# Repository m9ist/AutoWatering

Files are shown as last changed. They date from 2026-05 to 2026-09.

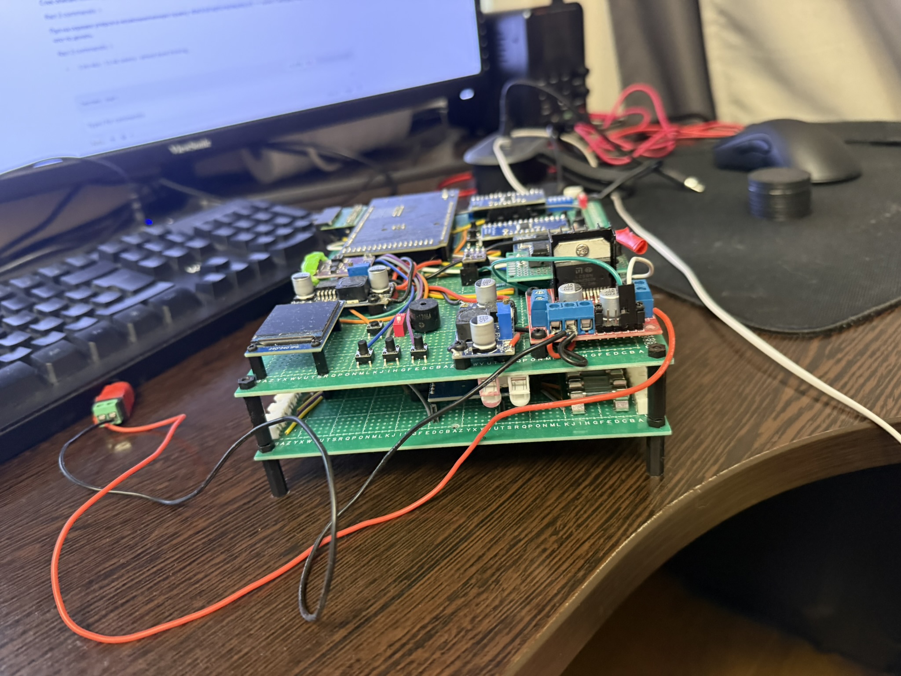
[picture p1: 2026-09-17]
docs/photos/IMG_0999.JPEG

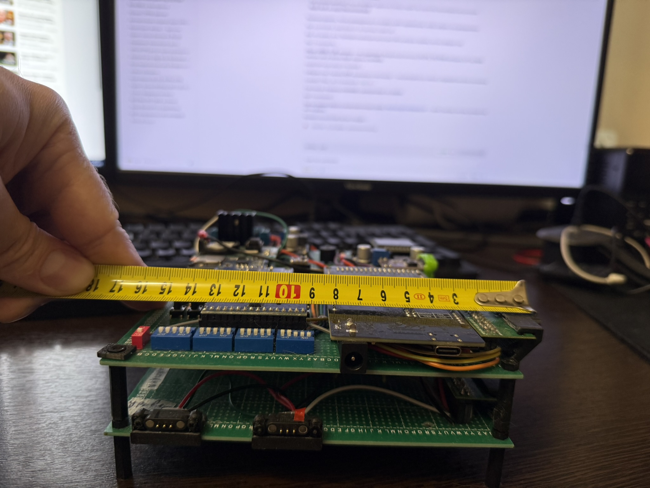
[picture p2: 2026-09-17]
docs/photos/IMG_0997.JPEG

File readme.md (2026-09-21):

# Автоматическая поливка растений

Система автоматического полива комнатных растений на базе Arduino Mega2560 + ESP8266. Поддерживает до 16 растений, управляется через Telegram, собирает данные с датчиков влажности почвы и отображает их на дисплее; логи и графики — в Grafana на домашнем сервере.

## Текущее состояние

- Проект в боевой эксплуатации (3–5 растений подключено)
- Управление поливом через Telegram-бота **aw-server** на домашнем сервере (`server/` этой репы)
- ESP — headless MQTT-шлюз: единственное соединение — локальный Mosquitto (см. [ADR-0001](docs/adr/0001-local-mqtt-broker.md))
- Логи ESP и метрики (температура, влажность воздуха, RAM, влажность почвы по растениям) — в Loki/Grafana, дашборд «Автополив»
- Уведомления в чат о переходах ESP онлайн/офлайн (LWT брокера)
- Ручной полив через кнопки на плате; ежедневный автополив — по команде `/daily`
- Диагностика подключения клапанов через датчик тока ACS712 (`/checkvalves`, кнопка на плате, статус в отчёте о каждом поливе)
- Оживление залипших после простоя клапанов: сухой прогон «дожим + щелчки» (`/wakeup`, либо кнопка проливки растения при выключенном тумблере помпы)

## Архитектура

```
[Telegram]        [Grafana/Loki (дашборд «Автополив»)]
     │                      ▲
     ▼                      │ логи + метрики
[aw-server]  ── Python-сервис на домашнем серваке (код: server/)
     │  команды aw/cmd ↓ · логи aw/log/# ↑ · стейт aw/state ↑ · события aw/event ↑
     ▼
[Mosquitto]  ── локальный MQTT-брокер (LAN, user/pass)
     ▲
     │ единственное внешнее соединение ESP
[ESP8266]    ── headless: WiFi, NTP, OTA, MQTT
     │  UART, текстовый JSON-протокол
[Arduino Mega2560] ── помпы, клапаны, датчики, дисплей, RTC, кнопки, SD-лог
```

**Arduino Mega2560** управляет всем железом, хранит стейт в EEPROM, исполняет команды полива, пишет логи на SD (офлайн-фолбэк).

**ESP8266** — тонкий шлюз: форвардит Команды из `aw/cmd` в UART (с валидацией границ), публикует кадр стейта Mega в `aw/state` как есть (retained), шлёт логи в `aw/log/esp` (при обрыве — RAM-кольцо с досылкой), держит LWT `aw/online`. Прошивается по OTA.

**aw-server** (Python, `server/`) — телеграм-бот (whitelist чатов), мост логов в Loki, метрики из стейта, уведомления о статусе ESP. Деплой — docker-стек в приватной инфра-репе homelab.

## Компоненты

| Компонент | Модель | Описание |
|---|---|---|
| Плата | Mega2560+WiFi-R3-AT328-ESP8266-32MB-CH340G | Arduino Mega + ESP8266 на одной плате |
| DC-DC преобразователь | LM2596S | 2 шт. Питание от внешнего БП 20V: один понижает до 5V (клапаны, электроника), второй до 12V (помпы) |
| Дисплей | IPS TFT ST7789 240×240 (ZJY-IPS130-V2.0) | Статус системы. [Схема подключения](https://simple-circuit.com/wp-content/uploads/2019/06/arduino-st7789-color-tft-240x240-pixel-interfacing-circuit.png) |
| RTC | DS1302 (чип DS1307) | Часы реального времени. [Документация](https://www.nookery.ru/ds1302-in-arduino/) |
| Помпа | R385 + драйвер MX1508 (чип L298N) | 2 шт. Перистальтические, активная выбирается из прошивки (ADR-0002). [Документация L298N](https://robotchip.ru/obzor-drayvera-motora-na-l298n/) |
| Клапаны | DC 5V HUXUAN электромагнитные | 16 шт, по одному на растение. Драйвер: WAVGAT ULN2003 5V 4-phase |
| Управление клапанами | 74HC595 сдвиговые регистры (3 шт) | Управление 16+ клапанами через 3 пина. [Урок](https://alexgyver.ru/lessons/74hc595/), [подключение](https://uscr.ru/kak-podklyuchit-sdvigoviy-registr-k-arduino/) |
| Датчики влажности почвы | HD-38 (SZYTF Soil Moisture Sensor) | 16 шт, аналоговые, ёмкостные. [Пример кода](https://github.com/vrxfile/test_arduino_sensors_modules/blob/master/capacitive_moisture_test/capacitive_moisture_test.ino), [описание](https://myduino.com/product/jhs-273/) |
| Мультиплексер | CD74HC4067 | 16-канальный, для датчиков влажности и кнопок. [Документация](https://arduinolab.pw/index.php/2017/07/17/16-kanalnyj-analogovyj-multipleksor-cd74hc4067/) |
| Датчик расхода воды | HESAI YF-S401 | Учёт пролитой воды в мл. [Документация](https://wiki.iarduino.ru/page/sensor-water-flow/) |
| Датчик тока | ACS712 20A | Диагностика клапанов |
| Датчик темп./влажности | GY-SHT30-D (чип SHT30) | Температура и влажность воздуха |
| Датчик уровня воды | XKC-Y25-NPN 5–12V | Бесконтактный. [Документация](https://wiki.amperka.ru/products:sensor-liquid-level-contactless) |
| SD-ридер | hw-125 (чип B108) | Логирование |

## Команды Telegram

Бот живёт в aw-server; команды принимаются только из whitelist-чатов.

| Команда | Описание |
|---|---|
| `/water plantX Yml` | Полить растение X на Y мл. Пример: `/water plant3 50ml` |
| `/config plantX Yml` | Установить дневную норму полива. Пример: `/config plant2 20ml` |
| `/state` | Последний стейт из retained `aw/state` (влажность, температура, свободная память, активная помпа) |
| `/daily` | Запустить ежедневный цикл полива вручную |
| `/checkvalves` | Проверить подключение всех активных клапанов (по дельте тока ACS712) |
| `/pump` | Переключить активную помпу на другую; результат — в `/state` |
| `/wakeup plantX [AxBms CxDms]` | Расходить залипший клапан X: щелчки всухую, помпа не включается. Без аргументов — `3x2000ms + 7x300ms`. Пример: `/wakeup plant3 5x1500 10x400` |
| `/help` | Справка по командам |

Графики влажности/климата — в Grafana (ASCII-графики в чате выпилены, issue [#20](https://github.com/m9ist/AutoWatering/issues/20)). Периодическая сводка стейта отключена (`HOURLY_SUMMARY_INTERVAL_S=0` в деплое).

## Начало работы

**Среда разработки:** [VS Code](https://code.visualstudio.com/) + [PlatformIO](https://platformio.org/platformio-ide)

Проект содержит две прошивки в `platformio.ini`:
- `megaatmega2560` — для Arduino Mega
- `esp` — для ESP8266 (загрузка по OTA на адрес `192.168.1.96`)

**Обязательные шаги перед сборкой:**

1. Создать файл `src/SecretHolder.cpp` (вне git) и реализовать методы:
   ```cpp
   String ssid()         { return "your_wifi_ssid"; }
   String wifiPasswork() { return "your_wifi_password"; }
   String mqttUser()     { return "esp"; }
   String mqttPassword() { return "<пароль учётки esp из sops стека mqtt>"; }
   ```

**Native-тесты** (парсер команд, RAM-кольцо логов, обработчик `aw/cmd`) — способ запуска описан в комментарии в конце `platformio.ini`.

**aw-server** (`server/`): Python 3.12, тесты `python -m pytest`; конфиг через env (см. `server/aw_server/config.py`). Деплой — стек `watering` в приватной репе homelab (там же брокер, стек `mqtt`).

## Протокол

**Arduino ↔ ESP (UART, JSON с ключом `"c"`):**

| Направление | Команда | Описание |
|---|---|---|
| ESP → Arduino | `esp_water` | Полить растение |
| ESP → Arduino | `esp_plant_conf` | Настроить дневную норму |
| ESP → Arduino | `esp_daily` | Запустить ежедневный полив |
| ESP → Arduino | `esp_check_valves` | Проверить подключение клапанов |
| ESP → Arduino | `esp_pump` | Переключить активную помпу на другую |
| ESP → Arduino | `esp_ntp` | Синхронизировать время |
| Arduino → ESP | `state` | Обновлённый стейт системы |
| Arduino → ESP | `arduino_tg` | Сообщение для человека (уходит Событием в `aw/event`) |

**MQTT (ESP ↔ aw-server, брокер Mosquitto):**

| Топик | Направление | Что | Retained |
|---|---|-----|---|
| `aw/cmd` | aw-server → ESP | JSON UART-протокола, passthrough (ESP валидирует границы) | нет |
| `aw/state` | ESP → aw-server | кадр `state` от Mega как есть | **да** |
| `aw/log/esp` | ESP → aw-server | строки лога `{ts, lvl, msg}` → Loki | нет |
| `aw/event` | ESP → aw-server | `{type, text}` — для Telegram | нет |
| `aw/online` | LWT | `1`/`0` — статус ESP (уведомления + панель в Grafana) | да |

## Калибровка расхода воды

Объём полива человек задаёт в миллилитрах, а помпа умеет только «крутиться
столько-то времени». Переводной коэффициент — практический расход помпы
в мл/с; по нему считается длительность автополива и `Expected ml` в отчёте.

Помпы физически разные, поэтому коэффициент у каждой свой
([src/Pomp.h](src/Pomp.h)):

| Помпа | Константа | Расход |
|---|---|---|
| 1 (main) | `POMP_FLOW_ML_PER_SEC_1` | 2.1 мл/с |
| 2 (spare) | `POMP_FLOW_ML_PER_SEC_2` | 3.2 мл/с |

Код берёт нужную через `pumpFlowMlPerSec(pumpIdx)` — в том числе на пробе
резерва, когда полив уходит на неактивную помпу.

Порядок калибровки:

1. Включить тумблер мотора (иначе кнопка запускает оживление клапана, а не
   полив), подставить под шланг растения мерный стакан.
2. Подержать кнопку проливки этого растения — льётся, пока кнопка нажата.
3. Взять из отчёта (экран и Telegram) `Expected ml` и записать реально
   налитый объём по стакану.
4. Новое значение = текущее × (налито по стакану / `Expected ml`). Несколько
   проливов разной длительности дают более честное среднее: короткие
   искажает разгон помпы.
5. Прописать новое значение в константу **той помпы, которая лила** (номер
   есть в том же отчёте, строка `Pump N`) и перепрошить Mega.

Кнопка на корпусе всегда льёт активной помпой — чтобы откалибровать вторую,
переключись на неё командой `/pump` и не забудь вернуть обратно.

Делить объём на `Duration` из отчёта нельзя: `Duration` — это весь полив
целиком, включая паузы по 200 мс на открытие и закрытие клапана, когда помпа
ещё (уже) не качает. `Expected ml` считается от окна работы самой помпы, так
что отношение «налито / Expected» этой погрешности не содержит.

`Real ml` в том же отчёте — показания расходомера YF-S401, они меряют то же
самое независимо, но сами нуждаются в проверке стаканом; ориентир при
калибровке — стакан, а не они.

Значение зависит от помпы, её скорости и высоты подъёма шланга — после любой
переделки гидравлики калибровку надо повторить, по каждой помпе отдельно.

## Известные проблемы и ограничения

- Физические соединения на pogo-pin разъёмах нестабильны — клапаны могут выпасть
- Ежедневный автозапуск полива по расписанию пока не реализован (только через `/daily`)
- Команды при офлайн-ESP не доставляются (clean-session + QoS0) — бот честно предупреждает в ACK
- Резерв помпы проверяется вероятностно (10% поливов уходят на неактивную помпу); при мёртвом резерве эти поливы уходят в никуда, вердикт выносит человек по `/state` (ADR-0002)
- У брокера нет ACL — доводка в issue [#19](https://github.com/m9ist/AutoWatering/issues/19)

## Команда проекта

- tg [@m9ist](https://t.me/m9ist)

---
*Используйте на свой страх и риск. Автор не компетентен в электронике.*

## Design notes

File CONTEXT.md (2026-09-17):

# Автополив

Система автополива до 16 комнатных растений: Mega2560 управляет железом,
ESP8266 связывает её с внешним миром через MQTT-брокер на домашнем серваке.

## Language

### Устройства и сервисы

**Mega**:
Arduino Mega2560, управляет железом (помпы, клапаны, датчики, дисплей, SD).
_Avoid_: ардуина (двусмысленно — ESP тоже Arduino-прошивка)

**ESP**:
ESP8266, headless-шлюз между Mega (UART) и брокером (MQTT). Своего
пользовательского интерфейса не имеет.

**aw-server**:
Серверный сервис на deb: телеграм-бот автополива, мост логов в Loki,
приёмник телеметрии. Код — в `server/` этой репы, деплой — в репе homelab.
_Avoid_: бот (это только одна из его ролей), мост

**Брокер**:
Локальный Mosquitto на серваке deb — единственная точка подключения ESP
и общая шина для будущих домашних интеграций.
_Avoid_: Dealgate (внешний брокер, ESP к нему не подключается — см. ADR-0001)

### Потоки данных

**Команда**:
JSON с ключом `c`, адресованный Mega. Формат един на всём пути
Telegram → aw-server → MQTT (`aw/cmd`) → ESP → UART; ESP валидирует
и форвардит, не переформатируя.

**Стейт**:
Снимок состояния системы (растения, климат, флаги), который Mega
периодически шлёт наверх. Последний стейт лежит retained в `aw/state`.

**Событие**:
Сообщение от ESP/Mega, предназначенное человеку в Telegram (подтверждения,
отказы Команд, тревоги). Публикуется в `aw/event`, доставляет aw-server.

**Лог-поток**:
Строки логов ESP, уходящие в `aw/log/esp` и далее в Loki. Дублируются
по старому пути UART → Mega → SD (офлайн-фолбэк).

### Полив

**Растение**:
Позиция 0..15: клапан + датчик влажности + дневная норма (мл).

**Дневной полив**:
Полив всех растений по их нормам одной командой (`/daily`); запускается
вручную, автозапуск по расписанию — в планах.

**Норма**:
Настроенный дневной объём воды растения, мл (`dailyAmountMl`).
_Avoid_: конфиг растения

**Помпа**:
Перистальтическая помпа R385 на драйвере MX1508. Их две: `pump1` (D6) и
`pump2` (D5) — номера позиционные и неизменные, роль «активная/резерв»
задаётся отдельно.
_Avoid_: насос, мотор

**Активная помпа**:
Помпа, на которой идут поливы (`State::activePump`). Переживает ребут,
меняется Командой `esp_pump` (`/pump` в Telegram). Вторая при этом —
резерв.

**Проба резерва**:
Полив, который с вероятностью 10% уходит на неактивную помпу вместо
активной, чтобы знать, жива ли она, до того как умрёт активная. В саммари
полива помечается `(spare probe)`. Вердикт «резерв мёртв» выносит человек
по `/state`, автоматики нет (ADR-0002).
_Avoid_: ротация помп, тест помпы

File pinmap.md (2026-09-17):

# Карта пинов Arduino Mega2560

Источник правды — код `D:\arduino\sketch_auto_watering\src`. Если код и эта таблица расходятся — побеждает код.

## Сводка по физическому разделению на 2 платы

Из `src/additinal_info.txt`: «Пины на нижней плате: 22-38d 0-7a».

| Плата | Что несёт | Пины Mega |
|---|---|---|
| **Верхняя (логическая)** | Mega+ESP-модуль, ST7789, RTC DS1302, MX1508 + 2 помпы, ACS712, SHT30, YF-S401, XKC уровень воды, hw-125 SD, пищалка, 4 кнопки UI, тумблер мотора | D2, D5, D6, D17, D19, D21, D27, D29, D31, D33, D37, D39, D41, D43, D45, D47, D50–D52, A0–A2, A12–A15 |
| **Нижняя (клапаны/датчики)** | 3× 74HC595 + 3× ULN2003, 16 клапанов, 3× CD74HC4067, 16 датчиков влажности, 16 кнопок проливки, 16 тумблеров клапанов | D18, D20, D26, D28, D30, D32, D34, D36, D38, A8–A11 |

Связь между платами — обычным кабелем (USB/гребёнка). На фабрике заказываем как 2 разные PCB.

## Цифровые пины Mega

| Пин | Назначение | Файл / макрос |
|---|---|---|
| **D2** | Датчик расхода воды YF-S401 (interrupt) | `Pomp.h` `PIN_WATER_FLOW_SENSOR` |
| **D5** | Помпа `pump2` (PWM → MX1508) | `Pomp.h` `PIN_POMP_SPARE` |
| **D6** | Помпа `pump1` (PWM → MX1508) | `Pomp.h` `PIN_POMP_MAIN` |
| **D17** | Тумблер мотора (физ. переключатель, INPUT_PULLUP) | `Pomp.h` `PIN_POMP_TURN_ON` |
| **D18** | SIG mux #3 — тумблеры клапанов 16шт (INPUT_PULLUP) | `Pomp.h` `PIN_MULTIPLEXER_PLANT_TURN_ON_SIG` |
| **D19** | I²C SDA → SHT30 | `Sensors.h` `PIN_TEMP_SDA` |
| **D20** | SIG mux #2 — кнопки проливки 16шт (INPUT_PULLUP) | `Pomp.h` `PIN_MULTIPLEXER_WATER_NOW_SIG` |
| **D21** | I²C SCL → SHT30 | `Sensors.h` `PIN_TEMP_SCL` |
| **D26** | Mux #1 S0 (датчики влажности) | `Sensors.h` `PIN_SERNSOR_S0` |
| **D27** | Кнопка выбора режима (INPUT_PULLUP) | `Screen.h` `PIN_MODE_BUTTON` |
| **D28** | Mux #1 S1 | `Sensors.h` `PIN_SERNSOR_S1` |
| **D29** | Кнопка вверх (INPUT_PULLUP) | `Screen.h` `PIN_UP_BUTTON` |
| **D30** | Mux #1 S2 | `Sensors.h` `PIN_SERNSOR_S2` |
| **D31** | Кнопка вниз (INPUT_PULLUP) | `Screen.h` `PIN_DOWN_BUTTON` |
| **D32** | Mux #1 S3 | `Sensors.h` `PIN_SERNSOR_S3` |
| **D33** | Кнопка проверки (INPUT_PULLUP) | `Screen.h` `PIN_CHECK_BUTTON` |
| **D34** | 74HC595 DS (data) | `Pomp.h` `PIN_REGISTER_DAT` |
| **D36** | 74HC595 STCP (latch) | `Pomp.h` `PIN_REGISTER_CS` |
| **D37** | TFT RES | `sketch_auto_watering.ino` `TFT_RES` |
| **D38** | 74HC595 SHCP (clock) | `Pomp.h` `PIN_REGISTER_CLK` |
| **D39** | TFT DC | `sketch_auto_watering.ino` `TFT_DC` |
| **D41** | RTC DS1302 ENA (RST/CE) | `AwClock.h` `PIN_ENA` |
| **D43** | RTC DS1302 DAT (I/O) | `AwClock.h` `PIN_DAT` |
| **D45** | RTC DS1302 CLK | `AwClock.h` `PIN_CLK` |
| **D47** | Пищалка (buzzer) | `AwLogging.h` `PIN_BUZZER` |
| **D50** | SPI MISO (hardware, не используется TFT'ом) | Mega hw |
| **D51** | SPI MOSI → TFT SDA (через делитель 5V→3.3V) | Mega hw |
| **D52** | SPI SCK → TFT SCL (через делитель 5V→3.3V) | Mega hw |

## Аналоговые пины Mega (часть в роли digital)

| Пин | Назначение | Файл / макрос |
|---|---|---|
| **A0** | Mux #1 SIG — 16 датчиков влажности почвы | `Sensors.h` `PIN_INPUT_SENSOR=0` (читается как `analogRead(0)`) |
| **A1** | Датчик уровня воды XKC-Y25 (analogRead, hi/lo) | `Sensors.h` `PIN_WATER_LEVEL` |
| **A2** | Датчик тока ACS712 | `Pomp.h` `PIN_AMPERAGE_SENSOR` |
| **A8** | Mux #2/#3 S3 (общая шина управления для двух кнопочных mux) | `Pomp.h` `PIN_PLANT_MULTIPLEXER_S3` |
| **A9** | Mux #2/#3 S2 | `Pomp.h` `PIN_PLANT_MULTIPLEXER_S2` |
| **A10** | Mux #2/#3 S1 | `Pomp.h` `PIN_PLANT_MULTIPLEXER_S1` |
| **A11** | Mux #2/#3 S0 | `Pomp.h` `PIN_PLANT_MULTIPLEXER_S0` |
| **A12** | SD (hw-125) MISO (software SPI!) | `AwLogging.h` `SD_MISO_PIN` |
| **A13** | SD MOSI | `AwLogging.h` `SD_MOSI_PIN` |
| **A14** | SD SCK | `AwLogging.h` `SD_SCK_PIN` |
| **A15** | SD CS | `AwLogging.h` `SD_CS_PIN` |

> SD на **программном** SPI (не на D50–D52), потому что hardware-SPI занят под TFT (даже если TFT работает только на запись, библиотека SdFat плохо уживается с делителями уровней — поэтому ушли на bit-bang на A12–A15).

## CD74HC4067 — 3 шт.

| # | Назначение | S0..S3 | SIG | Кол-во каналов |
|---|---|---|---|---|
| 1 | Датчики влажности почвы (HD-38) | D26/D28/D30/D32 | A0 | 16 |
| 2 | Кнопки проливки растений (тактильные) | A11/A10/A9/A8 (общие с #3) | D20 | 16 |
| 3 | Тумблеры включения растений (физические) | A11/A10/A9/A8 (общие с #2) | D18 | 16 |

## 74HC595 — 3 шт. в каскаде

Управление: DS=D34, SHCP=D38, STCP=D36. OE и MR — на VCC/GND статически.

В каждом регистре используется **только Q1..Q7** (7 выходов из 8). 3 × 7 = 21 канал, на клапаны идёт 16, остальные пустуют. Логика — в `Pomp.h::patchValveId`:

```c
if (id < 7)  return id + 1;   // valves 0..6  → register1.Q1..Q7
if (id < 14) return id + 2;   // valves 7..13 → register2.Q1..Q7
else         return id + 3;   // valves 14..15 → register3.Q1..Q2
```

С каждого регистра Q1..Q7 → IN1..IN7 соответствующего ULN2003 → клапан + флайбэк-диод (диод уже в ULN2003, отдельные не нужны).

## ULN2003 — 3 шт.

Стоят сразу после 74HC595, по одной на регистр. Питание (COM, pin 9) — от шины **5V клапанов** (отдельная от 5V логики).

**Важная особенность подключения клапанов:** ULN2003 — это сборка open-collector NPN, она **замыкает массу**, а не подаёт плюс. Поэтому:

- **+5V (шина клапанов)** подаётся на **все 16 клапанов** одной общей шиной (плюсовая ножка каждого клапана).
- **Минусовая ножка** каждого клапана уходит на индивидуальный выход OUT драйвера ULN2003.
- COM-пин ULN2003 (pin 9) тоже подключён к **+5V шины клапанов** — для встроенных freewheel-диодов.

**Что это даёт для кабельного хозяйства / будущей PCB-перепланировки:**
один толстый провод +5V (общий) + 16 сигнальных в плоском шлейфе. Хорошо для будущей архитектуры с отдельной саб-платой клапанов и USB-кабелем между платами.

## Силовая часть (as-is)

```
USB-C PD-trigger (модуль с DIP-switch, 5/10/15/20V) → 20V
   │
   ├── LM2596S #1 → 12V → MX1508 → 2 помпы R385
   │
   └── LM2596S #2 → 5V (общая шина) → клапаны через ULN2003
                                    + Mega (на пин 5V), регистры, мультиплексоры,
                                      датчики, дисплей через 3.3V LDO самой Mega
```

**Важно:** в текущей as-is одна общая шина 5V на всё. Разделение на «5V клапанов» и «5V логики» — в [backlog.md](backlog.md), на рефакторинг.

3.3V для TFT берётся с самой Mega; SPI-сигналы (SCK/MOSI/DC/RES) проходят через резистивные делители 5V→3.3V (R 2.2k + R 3.3k).

## Подключение MX1508 (помпы R385)

Реверс не нужен — помпы крутятся только в одну сторону. PWM на одном входе пары, второй вход — на GND:

| Канал MX1508 | Подключение |
|---|---|
| `pump1` | IN1 = D6 (PWM), IN2 = GND. Помпа между OUT1 и OUT2 (или OUT2 и GND, если плата так разведена). |
| `pump2` | IN3 = D5 (PWM), IN4 = GND. Аналогично. |

Питание VCC драйвера = **12V** (с LM2596S #1). Логическая сторона MX1508 (VCC IO) — обычно объединена с VCC-силовой, нужно проверить по конкретному модулю.

## Питание Mega

**Внешний 5V с LM2596S #3 идёт прямо на пин `5V` Mega-модуля** (минуя встроенный регулятор Mega). Та же шина уходит и на нижнюю плату (питание регистров, мультиплексоров, ULN2003 — последний только в COM, не на VCC).

USB-разъём Mega остаётся для прошивки/отладки, но в постоянной работе питание идёт по 5V-пину.

## Разъёмы на плате (as-is)

| Группа | Кол-во | Тип | Контактов | Где расположен |
|---|---|---|---|---|
| Клапаны | 16 | Pin header 2.54 мм (гребёнка под Dupont) | 2 (V+ и сигнал) | нижняя плата |
| Датчики влажности | 16 | Pin header 2.54 мм | 3 (V+, GND, A) | нижняя плата |
| Помпы | 2 | DC barrel jack 5.5×2.1 мм («DC 2.1») — кабель идёт от MX1508 | 2 (V, GND) | верхняя плата (рядом с MX1508) |
| YF-S401 расходомер | 1 | Pogo-pin 3-контакта (на плате — ответная часть) | 3 (V+, GND, signal) | нижняя плата |
| XKC-Y25 уровень воды | 1 | Pogo-pin 3-контакта | 3 (V+, GND, signal) | нижняя плата |
| SHT30 (I²C) | 1 | 2.54 мм гребёнка | 4 (V, GND, SCL, SDA) | верхняя плата |
| RTC DS1302 (модуль) | 1 | 2.54 мм гребёнка | 5 (VCC, GND, CLK, DAT, RST) | верхняя плата |

> **На рефакторинг:** заменить pin header'ы 2.54 мм на разъёмы с замком (KK 254 / JST EH 2.5 мм) — снимет проблему «клапаны выпадают» из исходного readme.

## Архитектура датчиков с pogo

Датчики (расходомер, уровень воды) — внешние устройства с 3-проводным кабелем. На конце кабеля припаян pogo, на плате — ответный pogo. Так датчик легко отстёгивается для обслуживания.

Дальше с pogo'a на плате:
- **V+ → шина 5V** (на той же плате)
- **GND → шина GND** (на той же плате)
- **Сигнал → межплатный USB → Mega** (на верхней плате — D2 для расходомера, A1 для уровня воды)

То есть pogo физически стоит на нижней плате, а сигнал везётся на верхнюю через межплатный кабель.

## Межплатный коннектор

На обеих платах стоит **USB 3.0 (тип A или B)**. Между платами — обычный USB 3.0-кабель, по 9 жил которого передаются: 5V, GND и нужные сигналы между нижней и верхней платой.

Маппинг конкретных сигналов на пины USB-разъёма зафиксируем при разводке.

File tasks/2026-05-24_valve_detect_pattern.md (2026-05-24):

# Задача: подобрать паттерн детекции подключённого клапана через ACS712

Дата: 2026-05-24

## Контекст

На линии питания клапанов стоит датчик тока ACS712 (пин `A2`). Уже есть базовая
функция `Pomp::checkValveConnected(id)` ([src/Pomp.h:326](../src/Pomp.h#L326)),
которая один раз включает клапан, мерит дельту тока и сравнивает с
`THRESHOLD_MA = 780`. Текущий порог не откалиброван (по комментарию рядом
дельта подключённого клапана ~131 mA, а сравнивается с 780 → всегда
DISCONNECTED).

Цель сегодня — **не править порог на глаз**, а собрать данные многократных
включений/выключений и понять, какой паттерн надёжно отличает «клапан
подключён» от «клапана нет».

## Тестовый стенд

- Slot **0** — клапан **подключён**.
- Slot **1** — клапана **нет** (висит «в воздухе»).
- Остальные слоты в этой сессии не используем.

Имея данные с этих двух соседних слотов, можно прямо сравнить распределения
и решить, по какому признаку отличать (дельта среднего, дисперсия,
N-из-M повторов и т.п.).

## Что делаем

### Идея измерения

Клапан — это соленоид. При подаче питания получаем **inrush-пик** тока в
момент открытия, дальше потребление падает. Используем сам факт пика как
критерий «клапан подключён»: на пустом слоте пика быть не должно.

Заранее не знаем ни длительности пика, ни формы кривой → **снимаем
полный профиль тока во времени** и анализируем уже на компе. На ардуине
никаких пороговых решений сегодня не принимаем.

#### Профиль одного ON/OFF цикла

- `base` — один замер `measureDcAvg(N_BASE_SAMPLES)` перед ON.
- **ON-окно**: 2 секунды с шагом 30 мс ⇒ ~67 точек.
- **TAIL-окно**: 1 секунда после OFF с шагом 30 мс ⇒ ~33 точки (смотрим
  спад; пригодится, если у пустого слота есть короткие выбросы и
  отличать придётся по форме, а не только по амплитуде).
- `GAP_BETWEEN_CYCLES_MS` — пауза перед следующим циклом.

Замеры за одну итерацию собираем в **локальные массивы int** на стеке
(~67 + 33 = ~100 элементов × 2 байта = ~200 байт). После цикла дампим
в Serial одной CSV-подобной строкой и переиспользуем буферы для
следующего цикла. На SRAM Mega2560 этого хватит без хип-фрагментации.

Грубый псевдокод одного цикла:

```
base = measureDcAvg(N_BASE_SAMPLES)
turnOnValve(id)
for k in 0..ON_SAMPLES-1:
    on[k] = ACS.mA_DC()
    wait_until(start_on + (k+1)*SAMPLE_PERIOD_MS)
    wdt_reset()
turnOffValve(id)
for k in 0..TAIL_SAMPLES-1:
    tail[k] = ACS.mA_DC()
    wait_until(start_off + (k+1)*SAMPLE_PERIOD_MS)
    wdt_reset()
dumpProbeLine(id, round, iter, base, on, tail)
delay(GAP_BETWEEN_CYCLES_MS)
```

Watchdog: текущий `WDTO_8S` ([sketch_auto_watering.ino:78](../src/sketch_auto_watering.ino#L78)).
Один цикл ≈ 2с + 1с + GAP + дамп ≈ 3.3с. `wdt_reset()` обязательно
**внутри** циклов замеров.

### Формат лога

Одна строка на цикл, чтобы потом легко распарсить:

```
VALVE_PROBE id=<id> round=<r> iter=<k> base=<mA> on=<v0>,<v1>,...,<v66> tail=<v0>,<v1>,...,<v32>
```

Сводку по слоту на ардуине считать **не нужно** — всё считаем на компе
по логу.

### Параметры (константы)

В начале метода:

- `N_BASE_SAMPLES = 10` — замеров для усреднённого baseline.
- `SAMPLE_PERIOD_MS = 30` — шаг между точками профиля.
- `ON_WINDOW_MS = 2000` ⇒ `ON_SAMPLES = ON_WINDOW_MS / SAMPLE_PERIOD_MS`.
- `TAIL_WINDOW_MS = 1000` ⇒ `TAIL_SAMPLES = TAIL_WINDOW_MS / SAMPLE_PERIOD_MS`.
- `GAP_BETWEEN_CYCLES_MS = 200` — клапан без тока закрывается быстро.
- `CYCLES_PER_PROBE = 3` — циклов ON/OFF на одну «проверку» слота.
- `ANCHOR_ROUNDS = 3` — раундов «якорь + рандом».
- `ANCHOR_SLOT = 0` — заведомо подключённый слот.

### Порядок прогона

Не просто `[0, 1]`, а с чередованием якоря и случайного слота, чтобы
исключить дрейф midpoint и сравнить подключённый клапан с
«заведомо пустым» в одних и тех же условиях:

```
повторить ANCHOR_ROUNDS раз:
    probe(ANCHOR_SLOT)            // 3 цикла ON/OFF на slot 0
    rnd = random(1, 16)           // 1..15, пустой слот на стенде
    probe(rnd)                    // 3 цикла ON/OFF
```

Итого на старте: 3 раунда × 2 слота × 3 цикла = **18 циклов** ON/OFF.
Время прогона ≈ 18 × 3.3с ≈ **60 секунд**.

### Интеграция

- **Новый публичный метод в `Pomp.h`** (рабочее имя
  `runValveProbe(AwLogging&)` — уточним при реализации).
- **Запуск** — из `loop()` в
  [sketch_auto_watering.ino:267](../src/sketch_auto_watering.ino#L267).
  Сейчас по `isCheckButtonPressed()` дёргается `sensors.tmpLoop`. Заменяем
  на вызов нового метода. `sensors.tmpLoop` пока трогать аккуратно — по
  умолчанию просто заменить вызов.
- **Помпу НЕ включаем** в этом сценарии. Только клапаны и ACS712.

## Что НЕ делаем сегодня

- Не подбираем финальный `THRESHOLD_MA` и не правим `checkValveConnected`
  по итогам одного прогона. Сначала смотрим данные, потом — отдельным
  шагом — калибруем.
- Не трогаем существующие диагностические логи в
  `startWaterPlant`/`stopWaterPlant` — они тоже про ток, но это другой
  сценарий (с помпой).
- Не выводим результаты в Telegram — пока только локальный лог через
  `AwLogging`.

## Критерий готовности

- Нажатие check-кнопки запускает прогон и в логе появляются строки с
  замерами по slot 0 и slot 1 (минимум по N=5 циклов на слот).
- По логу видно различие между подключённым (slot 0) и неподключённым
  (slot 1) клапаном — либо по средней дельте, либо по другому признаку,
  который мы сможем обсудить и взять за основу порога.
- Watchdog не срабатывает, скетч после прогона продолжает работать
  штатно.

## Результаты прогона 1 (2026-05-24)

Лог: [`2026-05-24_valve_detect_pattern.log`](2026-05-24_valve_detect_pattern.log).

Стенд: slot 0 подключён, рандомы — id=8 (round 0), id=5 (round 1), id=9 (round 2). Все три рандомных слота заведомо пустые.

### Сводка delta (avg/peak) по первым ~300 мс ON-окна

| Слот | avg delta, mA | peak delta, mA |
|---|---|---|
| id=0 (подключён, 8 валидных итераций) | **+167 … +406** (среднее ~+300) | **+265 … +499** |
| id=5, 8, 9 (пустые, 9 итераций) | **-205 … -108** | **-131 … -43** |

Запас между классами **≥ 200 mA** (худший подключённый +167 vs лучший пустой -43).

### Наблюдения

1. **Битый base в самой первой итерации:** `id=0 round=0 iter=0 base=19`. ACS не успевает прогреться после `autoMidPoint(100, 5)` в `initPomp` — первый реальный замер уже валидный (~18000–18200). Лечится «разогревом» перед началом probe.
2. **У пустых слотов on-значения часто НИЖЕ baseline на 100–200 mA.** Гипотеза: переключение бита в shift-регистре чуть «подсаживает» линию питания, через которую же течёт измеряемый ток. Контраст это не портит — наоборот увеличивает.
3. **Профиль подключённого клапана — НЕ резкий пик-и-спад.** Первая точка (t=0): +100…+200 mA. Плато t=30…300мс: +350…+500 mA. Дальше медленно спадает к +200…+300 mA и держится до 2 сек. То есть никакого короткого inrush нет — **клапан тянет постоянный ток всё время, пока открыт**. Можно мерить когда угодно в окне 30–500мс.
4. **TAIL после OFF неинформативен** — у всех слотов tail = base ± 100. Ток падает к baseline за <30мс. Окно можно выкинуть.

### Что это даёт для боевой `checkValveConnected`

- `base = measureDcAvg(10)` → `turnOnValve` → ждать ~50 мс → `active = measureDcAvg(5)` → `turnOffValve` → `delta = active - base`.
- Порог: **`delta > 150 mA`** → CONNECTED.
- Текущий `THRESHOLD_MA = 780` в [Pomp.h:327](../src/Pomp.h#L327) в 5 раз больше реального сигнала — отсюда «всегда DISCONNECTED».

Но сначала — прогон 2.

## План прогона 2

Уточнения по итогам прогона 1:

1. **Warmup ACS 2 секунды** перед первым `turnOnValve`. Лог отдельной строкой
   (`VALVE_PROBE_WARMUP samples=...`), чтобы увидеть, на какой секунде midpoint реально стабилизируется.
2. **`ON_WINDOW_MS_ANCHOR = 5000`** для anchor (slot 0) — убедиться, что потребление стабильно на дистанции 5 с.
3. **`ON_WINDOW_MS_EMPTY = 500`** для пустых слотов — экономим время, профиль и так плоский.
4. **3 разных рандомных пустых слота** между двумя anchor-проверками, выбираются без повторений из [1..15]. Цель — убедиться, что показатели одинаковые на всех слотах (нет «особенных» каналов в мультиплексере / shift-регистре).
5. `CYCLES_PER_PROBE_ANCHOR = 3`, `CYCLES_PER_PROBE_EMPTY = 1` (пустых много, повторы на каждом не нужны).
6. TAIL-окно — убрать.

Структура прогона:
```
warmup 2с
повторить ANCHOR_ROUNDS=3 раз:
    probe(ANCHOR_SLOT, ON_WINDOW_MS_ANCHOR) × CYCLES_PER_PROBE_ANCHOR
    pick 3 distinct random slots from [1..15]:
        for each: probe(slot, ON_WINDOW_MS_EMPTY) × CYCLES_PER_PROBE_EMPTY
```

Бюджет времени: warmup 2 + (3 × 5 × 3) anchor 45 + (3 × 0.5 × 3) empty 4.5 + GAP'ы ~3 + дампы ~5 ≈ **~60с**.

Размер массива samples: `max(ON_SAMPLES_ANCHOR=166, WARMUP_SAMPLES=66) = 166` int × 2 байта = 332 байта на стеке.

## Результаты прогона 2 (2026-05-24)

Лог: [`2026-05-24_valve_detect_pattern.2.log`](2026-05-24_valve_detect_pattern.2.log).

Стенд тот же: slot 0 подключён, рандомы — id=8/5/9 (round 0), id=9/11/3 (round 1), id=10/9/5 (round 2).

### Главное открытие: «фоновый» ток включается после первого ON и не выключается

Хронология самого начала прогона:

| Шаг | Значение | Что это значит |
|---|---|---|
| WARMUP 2с (66 точек) | **48 ± 49** | ACS midpoint откалиброван верно, фоновый ток ≈ 0 mA |
| base перед id=0 r0 iter=0 | **48** | подтверждает: до первого ON фоновый ток = 0 |
| on[0..165] первого ON | **17986 … 18181** | сразу скакнул к ~18000 mA |
| OFF + GAP 200мс + base для iter=1 | **18391** | **не вернулся** к 0 |
| Все последующие base | **18230 … 18391** | стабильная «новая нулевая» |

То есть после первого `turnOnValve` что-то в схеме (кандидаты: ёмкости по линии 12В, паразитный путь через ключ, гистерезис ACS) выходит на постоянное потребление ~18А и больше не отпускает. **Реальный ток клапана** — это дельта поверх этого фона, **+130…+400 mA** (как и в прогоне 1).

Прогон 1 этот эффект не показывал, потому что там autoMidPoint попал по другому фазе и фоновый ток считался baseline-ом с самого начала.

### Сводка по итерациям (без битой первой)

**Anchor (id=0), 5-секундное окно × 8 валидных итераций:**
- delta avg от base: **+130 … +200 mA**.
- delta peak: **+250 … +400 mA**.
- Профиль за 5 секунд **плоский** — никакого спада, ток стабилен от 30мс до 5000мс.
- `on[0]` (t=0) часто ниже `on[1]` (t=30) на 100–250 mA — соленоиду нужно ~30мс на выход на ток.

**Пустые слоты (3, 5, 8, 9, 10, 11), 0.5с × 9 проверок:**
- delta avg: **-205 … -73 mA**.
- Все 6 разных каналов одинаковые — **в shift-регистре/мультиплексере «особенных» слотов нет**.

### Запас разделения

Минимальная подключённая дельта avg (+130) vs максимальная пустая (-73) → **разрыв ≥ 200 mA**.
Threshold ~80–100 mA даёт надёжное разделение с большим запасом в обе стороны.

### Что это значит для боевой `checkValveConnected`

1. **Warmup ACS проблему НЕ решает** — она в линии питания, а не в датчике. Убирать warmup из боевого кода смысла нет, но и оставлять ради «разогрева ACS» тоже бессмысленно.
2. **Перед боевыми проверками нужен «фиктивный» первый ON-OFF**, чтобы поднять фоновый ток на стабильный уровень. Иначе первая боевая проверка даст delta ≈ +18000 → False Positive.
3. **Threshold = 80–100 mA** на дельту avg за окно 30–150 мс.
4. Окно ON можно сократить до **~100–150 мс** (сигнал устаканивается за 30мс, дальше плато).

### Открытый вопрос для прогона 3

Что именно триггерит «фоновые +18А» — `turnOnValve` подключённого клапана, или любой `shiftOut` / `turnOnValve` независимо от наличия клапана?

**Эксперимент:** в начале `runValveProbe` после warmup сделать **первый ON-OFF на пустом слоте** (например, фиксированный id=8), потом всё как сейчас.

- Если первая итерация пустого даст delta ≈ +18000 → эффект «прогрева» вызывается любым переключением регистра. «Фиктивный прогрев» в боевом коде можно делать на пустом слоте (или вообще на `sendNewStateValves` без открытия физического канала).
- Если первая итерация пустого даст delta ≈ 0 → эффект специфичен для реального тока через подключённый клапан. Тогда «прогрев» = реальный `checkValveConnected(<anchor>)` или подобный.

## План прогона 3

Минимальные правки в `runValveProbe`:
1. После warmup — сделать **один ON-OFF на фиксированном пустом слоте** (`PROBE_PRIMER_SLOT = 8`) с окном 0.5с. В логе помечается `round=-1`.
2. Anchor (slot 0) и пустые слоты — все по **0.5с × 1 цикл** (профиль плоский на 5с мы уже подтвердили в прогоне 2, повторно не нужно).
3. 3 раунда, в каждом: anchor + 3 разных рандомных пустых.

По данным сравним:
- profile **primer-цикла** (pure-первый ON-OFF после warmup) с profile «первой пустой проверки» из прогона 2 (там она шла после anchor) и с anchor-`iter=0` прогона 2.
- Главный вопрос: в primer (на пустом слоте) скакнёт ли фон до +18А, как в прогоне 2 скакнул на anchor.

Бюджет: warmup 2с + primer 0.5с + 3 × (anchor 0.5с + 3 пустых × 0.5с) ≈ **~10–15 секунд**.

## Результаты прогона 3 (2026-05-24)

Лог: [`2026-05-24_valve_detect_pattern.3.log`](2026-05-24_valve_detect_pattern.3.log).

Стенд тот же: slot 0 подключён; PRIMER на slot 8 (заведомо пустой).

### Гипотеза о фоновом токе — подтверждена

| Шаг | base | первые on[] | вывод |
|---|---|---|---|
| WARMUP 2с | — | все 0/48 | фон ≈ 0 |
| **PRIMER id=8 (пустой!) round=-1** | **19** | **18084, 18035, 18035, ...** | фон скакнул до ~18000 **на пустом слоте** |
| anchor id=0 r0 после primer | 18288 | 18279, 18426, ... | фон уже стабилен |

**Эффект «фоновый +18А» триггерится ЛЮБЫМ первым `turnOnValve`, независимо от подключённости клапана.** Значит для боевого кода primer можно делать на чём угодно — хоть на заведомо пустом слоте, хоть на первом из проверяемых.

### Сводка дельт прогона 3

**Anchor (id=0), 0.5с × 3 итерации:**
- r0: base=18288, on avg=18365 → delta avg = **+77**, max +187
- r1: base=18283, on avg=18330 → delta avg = **+47**, max +143
- r2: base=18298, on avg=18450 → delta avg = **+152**, max +274

**Пустые (3, 5, 9, 10, 11), 0.5с × 9 проверок:** delta avg = **-250 … -75**.

**Разрыв между классами:** минимум anchor (+47) vs максимум пустого (~-25 в max-delta, -75 в avg-delta) → **≥ 100 mA запас по avg**.

### Замечание о разбросе anchor-дельт между прогонами

| Прогон | Окно | Anchor delta avg | Anchor delta peak |
|---|---|---|---|
| 1 (первые 300 мс) | 300 мс | +167…+406 | +265…+499 |
| 2 (5с) | 5000 мс | +130…+200 | +250…+400 |
| 3 (0.5с после primer) | 500 мс | +47…+152 | +143…+274 |

Дельта в прогоне 3 заметно ниже, чем в 1 и 2. Причины достоверно неизвестны: измерительный шум на маленькой выборке (3 итерации), температура, давление воды, состояние конденсаторов, какие-то скрытые отличия в стенде. Для калибровки порога принимаем нижнюю границу из всех прогонов (+47) с запасом.

## Итоговые выводы по экспериментам

1. **Сигнал есть и устойчиво разделяет подключённый/пустой клапан.** Между минимальной подключённой и максимальной пустой дельтой — запас ≥ 100 mA даже в худшем прогоне.
2. **Профиль подключённого клапана — плоский.** На дистанции 5 секунд никакого спада, никакого специфического inrush. Мерить можно когда угодно в окне 30–500 мс после ON.
3. **TAIL после OFF неинформативен.** Ток возвращается к baseline за <30 мс.
4. **Фоновый ток ~+18А поднимается после первого `turnOnValve` в boot-цикле и держится до ребута.** Это не ток клапана — это паразитный эффект схемы (заряд ёмкостей / гистерезис / путь через ключ). Срабатывает на ЛЮБОМ первом ON независимо от подключённости.
5. Все каналы мультиплексера/shift-регистра дают **одинаковую** «пустую» картину — особенных слотов нет.
6. Текущая [Pomp.h:326 `checkValveConnected`](../src/Pomp.h#L326) с `THRESHOLD_MA = 780` нерабочая — реальная дельта в 5+ раз меньше и порог никогда не срабатывает.

## Боевая логика (черновик)

### Параметры

- `VALVE_CHECK_THRESHOLD_MA = 50` (с запасом от минимально наблюдённой anchor-дельты +47; ниже не опускаем, чтобы не цеплять шум). Калибруем по боевым прогонам.
- `VALVE_CHECK_ON_DELAY_MS = 50` (между `turnOnValve` и измерением active).
- `VALVE_CHECK_BASE_SAMPLES = 10`, `VALVE_CHECK_ACTIVE_SAMPLES = 5`.

### Алгоритм `checkValveConnected(id)`

```
base = measureDcAvg(VALVE_CHECK_BASE_SAMPLES)        // ~100 ms
turnOnValve(id)
delay(VALVE_CHECK_ON_DELAY_MS)                       // 50 ms
active = measureDcAvg(VALVE_CHECK_ACTIVE_SAMPLES)    // ~50 ms
turnOffValve(id)
delta = active - base
return delta > VALVE_CHECK_THRESHOLD_MA
```

~250 мс на один клапан. На 16 клапанов: ~4с.

### Primer

Фон надо «прогреть» **один раз после ребута**. Кандидаты по реализации:
- **A.** При каждом запросе на проверку — игнорировать результат первого вызова `checkValveConnected`, считая его primer-ом. Минус: пользователь не получит честный отчёт по первому слоту.
- **B.** Хранить флаг `bool primed` в `Pomp`. Перед первой проверкой делать «холостой» ON-OFF на фиксированном слоте (любом — хоть `ANCHOR_SLOT = 0`, хоть условном `PRIMER_SLOT`). Минус: ~150 мс лишних на первый запрос.
- **C.** Primer прямо в `initPomp`. Плюс — primer происходит «бесшумно» во время загрузки. Минус — открываем клапан на 150 мс при boot (если он подключён и в трубе вода — будет ~пара мл протёчки).

Решение — отдельно.

### Две точки использования

**1. Ручная проверка (Telegram + кнопка).**
- Команда `ESP_COMMAND_CHECK_VALVES` уже есть ([sketch_auto_watering.ino:175](../src/sketch_auto_watering.ino#L175)) — она дёргает `pomp.checkAllActiveValves(state, logger)` и шлёт результат в Telegram.
- Кнопка `isCheckButtonPressed` тоже вызывает `checkAllActiveValves` и шлёт результат в Telegram (та же функция).
- Проверяются **только активные** клапаны (с `PLANT_IS_ON`).
- `runValveProbe` и весь диагностический обвес (циклы `for(i=0;i<20;i++)` в start/stop WaterPlant, `checkAmperage`) — удалить.

**2. Мониторинг тока во время полива.**
- НЕ проверка клапана через дельту (это разовый ручной сценарий). Это контрольный сенсор «всё ли идёт как надо», аналог датчика расхода воды.
- В `waterPlant(id, amount)` параллельно работающей помпе и открытому клапану в цикле снимаем `ACS.mA_DC()` каждые ~500 мс (`AMP_SAMPLE_EVERY_ITER = 5`).
- Каждый сырой замер — в лог отдельной строкой (`Water amp: <mA>mA`).
- В строку, возвращаемую из `waterPlant`, добавляется avg — `Amperage avg: <mA>mA`. Дальше она уходит в Telegram через `sendTelegram` в [sketch_auto_watering.ino:113](../src/sketch_auto_watering.ino#L113).
- Здесь измеряется **общий** ток в линии (фоновый +18А, плюс ток помпы, плюс ток клапана). Никаких порогов сейчас не накладываем — это сбор данных для последующей калибровки контроля.

### Primer-стратегия

- Поле `bool acsPrimed = false` в `Pomp` (сбросится только при ребуте).
- Метод `primeAcsLineIfNeeded(logger)`: при первом вызове — холостой `turnOnValve(PRIMER_SLOT) → delay 150 → turnOffValve → delay 200`, ставит флаг.
- `PRIMER_SLOT = 0` — для тестов; для боевого реально пофиг (помпа выключена, протечки практически нет).
- Вызывается в начале `checkAllActiveValves` и в начале `waterPlant` (через единый хелпер).

## Открытые вопросы (на потом, по данным)

- Нужно ли менять `SAMPLE_PERIOD_MS` (30 мс) — поймём по форме кривой
  в логе. Если пик окажется уже одного отсчёта — уменьшаем; если ничего
  интересного не происходит — увеличиваем и берём окно длиннее.
- Длина `ON_WINDOW_MS` / `TAIL_WINDOW_MS` — увидим по затуханию,
  достаточно ли.
- `GAP_BETWEEN_CYCLES_MS = 200` — если по tail видно, что ток не успел
  упасть к baseline, увеличиваем.

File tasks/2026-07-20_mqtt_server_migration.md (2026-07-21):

# Переезд ESP на локальный MQTT: логи в Loki, телеграм-бот на серваке

Дата: 2026-07-20. Решения зафиксированы в грилинг-сессии;
архитектурное — в [`../docs/adr/0001-local-mqtt-broker.md`](../docs/adr/0001-local-mqtt-broker.md),
термины — в [`../CONTEXT.md`](../CONTEXT.md).
Заменяет план [`2026-07-04_mqtt_dealgate_implementation_plan.md`](./2026-07-04_mqtt_dealgate_implementation_plan.md)
в части «ESP → Dealgate напрямую».

## Контекст

- Телеграм на ESP сейчас **не работает** (блокировки/VPN) — у системы нет канала
  управления, кроме железа. Это главный драйвер приоритетов.
- На серваке deb уже есть Loki + Alloy + Grafana (этап 2 мониторинга, 2026-07-18)
  и VPN-слой с failover (проблема доступа к Telegram API решена).
- Веб-морда Гравера (SettingsGyver) давала только лог 2500 байт в RAM,
  PlotStack и мёртвую кнопку — всё это заменяется серверным наблюдением.

## Архитектура

```
[Telegram]                    [Алиса — потом, на стороне сервака]
    │                                  │ (mosquitto-bridge в Dealgate или «Маша»)
    ▼                                  ▼
[aw-server, Python, docker]   ← код в server/ этой репы, деплой в homelab
    │  ├─ телеграм-бот (тот же токен, whitelist чатов)
    │  ├─ aw/log/#  → Loki push API  (метки stack=watering, service=esp)
    │  └─ aw/cmd ←→ aw/event, aw/state
    ▼
[Mosquitto]  ← homelab/stacks/mqtt: порт 1883 в LAN, user/pass в sops, без TLS,
    ▲          отдельные учётки для esp и aw-server
    │ PubSubClient, единственный брокер
[ESP8266]  ── headless: OTA + UART + MQTT
    │ UART (протокол не меняется)
[Mega2560] ── не трогаем: SD-логи и приём логов ESP на SD — как есть
```

## Решения (из грилинга)

| # | Вопрос | Решение |
|---|---|---|
| 1 | Веб-морда ESP | Нет. Headless, наблюдение в Grafana |
| 2 | Транспорт | MQTT — универсальная шина (логи + команды + будущая Алиса) |
| 3 | Брокеры | Один локальный Mosquitto; Алиса потом мостом на серваке (ADR-0001) |
| 4 | Телеграм-бот | Отдельный сервис aw-server; PicoClaw не трогаем |
| 5 | Гранулярность | Один сервис: бот + мост MQTT→Loki в одном процессе |
| 6 | Стек aw-server | Python (paho-mqtt + telegram-lib + requests в Loki) |
| 7 | Логи Mega / SD | Не трогаем: в Loki только логи ESP; SD-путь (в т.ч. ESP→Mega→SD) как есть |
| 8 | Команды | JSON-passthrough: `aw/cmd` несёт тот же JSON, что UART-протокол |
| 9 | Обрыв брокера | RAM-кольцо ~2–4 КБ с досылкой при реконнекте |
| 10 | Брокер деплой | Отдельный стек homelab/stacks/mqtt (общий для дома, Джарвис подключится к нему же) |
| 11 | Порядок | Сервак → ESP (см. этапы) |

Микро-решения:
- Часовые сводки стейта в Telegram планирует **бот** (из retained `aw/state`);
  `/state` отвечает бот без похода на ESP; таймер `timerStateSendTelegram` с ESP уходит.
- ASCII-графики остаются на ESP: `/graphs` → `aw/cmd` → ESP рендерит Graph.h →
  текст назад через `aw/event` → бот пересылает в чат.
- Метрики в Grafana — следующий шаг после логов: парсить из лог-строк
  (стейт публикуется как JSON — LogQL распарсит), отдельный пайплайн метрик не строим.

## Топики и форматы

| Топик | Направление | Payload | Retained |
|---|---|---|---|
| `aw/log/esp` | ESP → сервер | JSON `{ts, lvl, msg}` | нет |
| `aw/state` | ESP → сервер | JSON стейта (как в UART `state`) | **да** |
| `aw/event` | ESP → сервер | JSON `{type, text}` — для Telegram | нет |
| `aw/cmd` | сервер → ESP | JSON UART-протокола (`c`: esp_water, …) | нет |
| `aw/online` | LWT + on-connect | `1` / `0` | да |

Timestamp для Loki ставит aw-server при приёме; `ts` от ESP остаётся в теле строки.

## Этапы

### Этап 1. Брокер (homelab)
Стек `homelab/stacks/mqtt`: Mosquitto, 1883 в LAN, учётки esp/aw-server в sops.
**Критерий:** `mosquitto_pub`/`sub` с компа через LAN работают с паролем, аноним отлуплен.

### Этап 2. aw-server (эта репа, `server/`)
Python-сервис: подписка `aw/#`, пуш `aw/log/#` в Loki, телеграм-бот
(команды `/water`, `/config`, `/state`, `/graphs`, `/daily`, `/checkvalves`, `/help`,
whitelist чатов), публикация команд в `aw/cmd`, пересылка `aw/event` в чат,
часовые сводки из `aw/state`. Деплой-обвязка — в homelab.
**Критерий:** без ESP — руками опубликованная строка в `aw/log/esp` видна в Grafana
(«Логи — Loki», `{stack="watering"}`); `/water plant2 50ml` в чате порождает
корректный JSON в `aw/cmd`; строка в `aw/event` прилетает в чат.

### Этап 3. Прошивка ESP (одним заходом)
- Вырезать: SettingsGyver + `sets::Logger`, UniversalTelegramBot,
  `WiFiClientSecure`/BearSSL, Yandex IoT (`sendMessageToIOT`, сертификаты
  и мёртвые методы SecretHolder), DEVFULL, `updatedSettings`.
- Добавить: PubSubClient → Mosquitto (reconnect, LWT `aw/online`);
  логгер за прежним интерфейсом (Serial + UART→SD как раньше + MQTT
  с RAM-кольцом и досылкой, маркер «reconnected, N строк потеряно»);
  подписка `aw/cmd` (валидация bounds остаётся) → форвард в UART;
  публикация `aw/state` retained на каждый стейт, `aw/event` вместо
  `logTelegram`, рендер `/graphs` по команде из `aw/cmd`.
- `platformio.ini`: убрать gyverlibs/Settings, DEVFULL, UniversalTelegramBot.
**Критерий:** логи ESP в Grafana; `/water` из Telegram доходит до полива;
`/graphs` возвращает ASCII; `aw/online` переключается при ребуте ESP;
OTA и UART-обмен с Mega не регрессировали.

### Этап 4. Дашборд «Автополив» в Grafana
Панель логов `{stack="watering"}` + статус `aw/online`.
**Критерий:** отладка полива не требует ничего, кроме Grafana и Telegram.

## Идеи (сознательно не в скоупе)

- PNG-графики из Grafana (grafana-image-renderer) вместо ASCII в Telegram.
- Логи Mega по UART → ESP → Loki (единый поток обоих контроллеров).
- Метрики влажности из логов → полноценные панели (шаг после этапа 4).
- Алиса: mosquitto-bridge в Dealgate ИЛИ навык «Маша» (ТЗ Джарвиса) — отдельное решение.
- Единый лог Mega+ESP, отказ от SD.

## Статус реализации (актуализировано 2026-07-21)

Все этапы 1–4 реализованы и задеплоены (тикеты #12–#18 + внутреннее ревью и
ревью GLM с фиксами). Отклонения от плана, принятые по ходу:

- **ASCII-графики выпилены целиком** (issue #20, пересмотр микро-решения 2):
  Graph/PointsHoler/`esp_graphs`/`/graphs` удалены; метрики (t, h, ram,
  влажность почвы по растениям) aw-server извлекает из живого aw/state и пушит
  в Loki (esp-state/esp-plant), панели — в дашборде «Автополив». Идея
  «метрики парсингом из логов LogQL» реализована именно так, отдельного
  пайплайна метрик по-прежнему нет.
- **aw/state — passthrough**: ESP публикует кадр Mega как есть, без
  deserializeState/serializeState (лишние поля "c"/"timestamp" сервер игнорирует).
- **Часовая сводка отключена** (HOURLY_SUMMARY_INTERVAL_S=0, решение
  2026-07-21); код поддерживает любой интервал.
- **Уведомления о переходах aw/online в чат** — замена старого
  «Esp started successfully», плюс офлайн-сторона через LWT.
- Микро-решение 1 (сводки планирует бот) — реализовано, но сводка выключена;
  /state отвечает из retained с учётом неизвестного возраста после рестарта.

2026-07-21: прошивка залита и проверена на железе владельцем — тикеты
#13/#15/#16/#17/#20 и зонтик #11 закрыты, миграция завершена.
Не закрыто: ACL брокера (#19), имена растений в PLANT_NAMES (стек watering).

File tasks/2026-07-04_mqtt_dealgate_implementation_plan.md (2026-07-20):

# Внедрение MQTT (Dealgate) в автополив — план реализации

> ⚠️ **Superseded 2026-07-20:** прямое подключение ESP к Dealgate отменено —
> ESP говорит только с локальным Mosquitto ([ADR-0001](../docs/adr/0001-local-mqtt-broker.md)),
> Алиса — потом мостом на серваке. Актуальный план:
> [`2026-07-20_mqtt_server_migration.md`](./2026-07-20_mqtt_server_migration.md).
> Исследование Dealgate (лимиты, умения, JSON key) остаётся полезным для будущего моста.

Дата: 2026-07-04
Продолжение исследования: [`2026-05-26_yandex_alice_integration.md`](./2026-05-26_yandex_alice_integration.md)

## Цель

Подключить ESP8266 к MQTT-брокеру **Dealgate** (`mqtt.dealgate.ru`, без TLS) и решить две задачи:

1. **Телеметрия** — публикация показаний в брокер (и в Алису):
   - температура воздуха, влажность воздуха;
   - CO₂ (датчик появится, пока готовим структуру);
   - влажность почвы по каждому растению (до 16 шт.).
2. **Команда «полей 25 мл растение №2»** — произвольный объём полива конкретного
   растения из приложения Алисы (и по возможности голосом).

## Что выяснено из доков Dealgate (исходники)

Сводка фактов с привязкой к страницам справки (скачаны 2026-07-04):

### MQTT-сервер ([help/4](https://dealgate.ru/help/4.html))
- **Host:** `mqtt.dealgate.ru` (домен, не IP). **Port:** из профиля (≈1883), без TLS.
- **Протокол:** MQTT 3.1 / 3.1.1 / 5.0 → `PubSubClient` (3.1.1) подходит.
- **Username / Password:** латиница + цифры + `_@`, задаются в профиле. Сменa пароля — сразу.
- **ClientID:** обязателен, уникален; два устройства с одинаковым ID = разрыв соединения; пустая строка запрещена; **зарезервированы** `dashboard`, `yandex`, `scenario`. Допустимые символы: латиница/цифры + `_@#$%&:-/`.
- **LastWill** и **KeepAlive** поддерживаются.
- **Топики:** UTF-8, **нельзя `$`**, не могут быть пустыми, чувствительны к регистру,
  **могут содержать пробел**, могут состоять только из `/`, без NULL.
  ⚠️ **Пространство топиков — глобальное на весь сервис** (в доке нет изоляции по юзеру).
  ⇒ обязателен уникальный префикс (например, username или случайный токен).
- **Лимиты:** 300 публикаций/мин, 300 авторизаций/мин, 6 неудачных авторизаций/мин,
  30 ошибок протокола/мин. Нарушителю режут трафик/отзывают логин. Нам с огромным запасом.

### Устройства и умения ([help/5](https://dealgate.ru/help/5.html))
- Устройство создаётся **виртуально** в кабинете, затем «привязывается» к реальному через MQTT.
- **Тип устройства** (переключатель/лампа/розетка/терморегулятор/окно,ворота,кран/шторы)
  **технически ни на что не влияет** — нужен только для голосовой семантики
  («кран открывать», «розетку включать»). Для полива берём тип **«кран»**.
- **Умения** (capabilities), по группам:
  - **Тумблер** — поля `MQTT topic` + **значение для ON** + **значение для OFF**
    (точные payload-строки задаём мы сами). ⇒ on/off команда.
  - **Регулятор** — `min`, `max`, `step`; единица зависит от типа
    (температура → °C, и т.д.). ⇒ произвольное число из диапазона.
  - **Режим** — >2 состояний, упорядоченных по номеру (порядок критичен);
    после привязки к Алисе менять нельзя.
  - **Датчик/сенсор** — только чтение; есть «Датчик MQTT» (несовместим с Алисой,
    но виден в панели Dealgate, со своим именем и единицей).
- У одного устройства может быть **несколько умений**.
- После привязки к Алисе редактирование запрещено — нужно сначала отвязать.

### JSON-формат ([help/15](https://dealgate.ru/help/15.html)) — ключевое для телеметрии
- В настройках умения можно задать **JSON key** — брокер сам извлечёт значение из
  опубликованного JSON (для датчиков) или завернёт команду.
- Поддержка массивов `[ ]` и вложенных объектов через точку: `Ds18b20.Value`, `pin[0]`,
  `[1].pressure`. ⇒ **одно сообщение-состояние может кормить сразу много умений**
  через разные JSON-ключи.

### История/графики ([help/10](https://dealgate.ru/help/10.html))
- Данные копятся в БД брокера (хранение 1 год), если топик привязан к умению.
- Графики строятся автоматически. ⇒ бесплатные графики в кабинете без своего кода.

### Сценарии ([help/12](https://dealgate.ru/help/12.html))
- Серверная визуальная автоматизация между умениями (не нужен свой код).
- Пригодится для «полей всё разом» (сценарий дёргает 16 on/off). Опционально.

## Архитектура

```
[Приложение/голос Алисы]
   │  Yandex УДЯ (навык Dealgate, без своей Cloud Function)
   ▼
[Dealgate: навык → MQTT-брокер]   mqtt.dealgate.ru:1883, без TLS
   │  MQTT 3.1.1  (PubSubClient поверх обычного WiFiClient)
   ▼
[ESP8266]  ← подписки на командные топики; публикация state в retained-топик
   │  UART JSON (существующий протокол Communication.cpp)
   ▼
[Arduino Mega 2560]  помпа, клапаны, датчики (SHT31 +未来的 CO₂ + влажность почвы)
```

Параллельные каналы остаются: **Telegram-бот** (нужен `WiFiClientSecure`) и **Gyver/OTA**.
⚠️ Telegram использует TLS — **`WiFiClientSecure` оставляем для него отдельным клиентом**,
а MQTT поднимаем на обычном `WiFiClient`. Это два разных объекта.

## Схема MQTT-топиков и пейлоадов

Префикс `aw` уникализируем юзернеймом/токеном: `<user>/aw/...`.
Ниже `BASE = "<user>/aw"`.

| Назначение | Топик | Payload | Retained | Направление |
|---|---|---|---|---|
| Состояние (всё сразу) | `BASE/state` | JSON (см. ниже) | **да** | ESP → broker |
| Online/offline | `BASE/lwt` | `ON` / `OFF` | да | LWT + on-connect |
| Полив вкл (по умолчанию) | `BASE/p/<n>/power` | `1` (ON) / `0` (OFF) | нет | broker → ESP |
| Полив N мл (объём) | `BASE/p/<n>/vol` | `<число мл>` | нет | broker → ESP |
| Проверить клапаны | `BASE/cmd/check` | `1` | нет | broker → ESP |
| Дневной полив | `BASE/cmd/daily` | `1` | нет | broker → ESP |

Payload `BASE/state` (одно сообщение кормит все датчики через JSON key):
```json
{"t":24.5,"h":48.2,"co2":612,"ram":4321,
 "p":[{"id":0,"on":1,"or":321,"m":25},{"id":2,"on":1,"or":450,"m":40}]}
```
Привязка JSON key в кабинете (примеры):
- датчик температуры → `t`; влажность воздуха → `h`; CO₂ → `co2`;
- влажность почвы растения N → `p[N].or` (или отдельный топик на растение — см. «Дизайн-решения»).

## Как решается задача 1 (телеметрия)

1. ESP получает `ARDUINO_COMMAND_STATE` от Mega по UART (уже работает,
   `processMessageArduino` в [`EspMain.cpp`](../src/EspMain.cpp)).
2. Сериализуем state в JSON (расширяем `serializeState` в [`State.h`](../src/State.h)):
   добавляем `co2`, при желании переименовать/оставить `t`,`h`.
3. Публикуем в `BASE/state` **с retained-флагом** каждый раз при свежем state,
   а также сразу после (re)connect к брокеру.
4. В кабинете Dealgate создаём **датчики** (температура/влажность/CO₂/почва N),
   каждый指向 топик `BASE/state` со своим **JSON key**.
5. Алиса при query читает последнее retained-значение → озвучивает.
6. История/графики копятся в кабинете автоматически (бонус).

⚠️ **Retained у Dealgate в доке не упомянут** — это главный риск задачи 1.
Проверяем опытно на Этапе 1. Если retained не работает — mitigation: публиковать
state по таймеру (каждые 1–5 мин) + отвечать на RPC-запрос (см. «Открытые вопросы»).

## Как решается задача 2 («полей 25 мл растение 2»)

У УДЯ `range` поддерживает instance **`volume`** ⇒ можно передать произвольное число.
Подтверждено из доки: регулятор публикует само число в свой topic.

**Рекомендуемая модель — устройство «Кран: Полив растения N» с двумя умениями:**
- **Тумблер «Питание»** → topic `BASE/p/<n>/power`, ON=`1`/OFF=`0`.
  Включение = полить на `dailyAmountMl` (стандартная норма). Голосом: «Алиса, полей цветок 2».
- **Регулятор «Объём»** (instance `volume`, 0…500 мл, step 5) → topic `BASE/p/<n>/vol`.
  Любое пришедшее число X трактуем как «полить X мл прямо сейчас» и вызываем
  `serialCommandWater(n, X)`. Приложение — точно работает; голос («установи объём… на 25»)
  проверяем опытно.

**Почему это работает технически:** на Mega `waterPlant(id, amount)` уже принимает
произвольный мл ([`sketch_auto_watering.ino:167`](../src/sketch_auto_watering.ino)),
а `serialCommandWater(id, amount)` в EspMain уже формирует нужный UART-JSON.
То есть новое — только распарсить число из MQTT и вызвать существующую функцию.

**Альтернативы (запасные):**
- Только тумблер + `mode`-пресеты «мало/средне/много» (Dealgate `mode` поддержан) —
  голос дружелюбнее, но без произвольного мл.
- Командный топик с JSON `{"plant":2,"ml":25}` — но Алиса из голоса такой payload
  не сгенерирует (только фиксированные ON/OFF, число range или выбор mode).

UX-нюанс: после полива «по объёму» регулятор в приложении останется showing значение X.
Опционально обратно публиковать туда `dailyAmountMl` как «текущее». Не блокирует MVP.

## Изменения в коде

### `src/SecretHolder.cpp`
- **Удалить:** Yandex-топики (`topic_commands/events/config/state`) и сертификаты
  `publicCert()` / `privateCert()` (TLS для IoT больше не нужен).
- **Добавить:**
  ```cpp
  const char* mqtt_host     = "mqtt.dealgate.ru";
  const uint16_t mqtt_port  = 1883;
  const char* mqtt_user     = "<из профиля>";
  const char* mqtt_pass     = "<из профиля>";
  const char* mqtt_client_id = "<уникальный, не dashboard/yandex/scenario>";
  const char* mqtt_base     = "<user>/aw";   // уникальный префикс
  ```
- **Оставить:** `ssid()`, `wifiPasswork()`, `getTelegramBotToken()`.

### `src/EspMain.cpp` (основная работа)
- **Клиенты:** переименовать существующий `WiFiClientSecure espClient` →
  `wifiClientSecure` (для Telegram). Добавить `WiFiClient wifiClient;` (для MQTT).
  `UniversalTelegramBot` пересоздать на secure-клиенте.
- **MQTT-объект:** `PubSubClient mqttClient(wifiClient);` + в `setup()`
  `mqttClient.setBufferSize(1024);` (state-JSON > дефолтных 256 байт PubSubClient!),
  `mqttClient.setServer(mqtt_host, mqtt_port);`,
  `mqttClient.setCallback(mqttCallback);`,
  `mqttClient.setKeepAlive(30);`.
- **Новые функции:**
  - `void mqttCallback(char* topic, byte* payload, unsigned int len)` — парсит topic
    (`BASE/p/<n>/power`, `BASE/p/<n>/vol`, `BASE/cmd/check`, `BASE/cmd/daily`),
    вызывает `serialCommandWater`/`serialLog(ESP_COMMAND_*)`. Парсинг `<n>` из топика.
  - `bool mqttConnect()` — `connect(clientId, user, pass, "BASE/lwt", 1, true, "OFF")`,
    после успеха подписки + публикация `BASE/lwt = ON` и текущего `BASE/state`.
  - `void mqttLoop()` — если `!mqttClient.connected()` → `mqttConnect()`; иначе
    `mqttClient.loop()`. Вызывать **первой строкой `loop()`** (нельзя допускать
    больших задержек, иначе брокер рвёт соединение).
  - `void publishState(const State&)` — собирает JSON через `serializeState`,
    `mqttClient.publish("BASE/state", json, true)`.
- **Интеграция:**
  - В `setup()` после `checkWifi()` — `setupMqtt()` (setServer/buffer/callback),
    первый `mqttConnect()`.
  - В `loop()` первой строкой — `mqttLoop();`.
  - В `processMessageArduino` по `ARDUINO_COMMAND_STATE` — `publishState(lastState)`
    (замена вызову `sendMessageToIOT`).
- **Удалить мёртвый код:** `sendMessageToIOT` (REST к IoT Core) и TLS-обвес
  `setupWifiClient` с Yandex-сертификатами. Часть `setupWifiClient`, относящуюся к
  Telegram-secure (`setInsecure`, `setBufferSizes`), перенести в отдельный
  `setupTelegramClient()`.

### `src/State.h` (и Mega-сторона)
- Добавить поле `int co2 = 0;` (ppm) в `State`; добавить в `serializeState`/`deserializeState`
  как ключ `co2`. Поднять `EEPROM_VERSION`, если CO₂ хранится в EEPROM.
- На Mega: завести чтение CO₂-датчика и заполнение `global_state.co2`
  (зависит от выбранного датчика — MH-Z19/MH-Z1311A/SCD41 по UART/SoftwareWire).

### `platformio.ini`
- `PubSubClient@^2.8` уже в `lib_deps` окружения `esp` ✓ — изменений не требуется.
- Убедиться, что окружение `esp` собирается после правок (`pio run -e esp`).

## Поэтапный план

### Этап 0. Кабинет Dealgate (без кода)
1. Профиль → выбрать порт, задать `Username`/`Password`. Записать в `SecretHolder`.
2. Придумать уникальный `mqtt_base` (юзернейм + токен), ClientID для ESP.
3. Создать виртуальные устройства:
   - **Датчики** на топик `BASE/state` с JSON key: температура `t`, влажность `h`, CO2 `co2`.
   - Несколько **кранов «Полив растения N»** (для MVP хватит 3–4 ключевых;
     все 16 раздуют каталог и могут упереться в лимит — см. «Риски»). Умения:
     тумблер `power` (ON=`1`/OFF=`0`) + регулятор `volume` `vol` (0…500, step 5).
   - Кнопки-сценарии: «Проверить клапаны» (`BASE/cmd/check`), «Дневной полив» (`BASE/cmd/daily`).
4. Привязать навык **Dealgate** в «Доме с Алисой», убедиться, что устройства видны.
5. **Опытно проверить retained**: опубликовать MQTT-клиентом (mosquitto_pub /
   MQTT Explorer) значение в `BASE/state`, закрыть клиент, запросить у Алисы —
   ответит ли? Зафиксировать результат (от него зависит стратегия публикации).
**Критерий:** в приложении Алисы переключение «крана» меняет последнее значение
в диагностике Dealgate (без железа).

### Этап 1. ESP: телеметрия (задача 1)
1. Рефакторинг клиентов: `WiFiClient` + `WiFiClientSecure` (Telegram).
2. `PubSubClient`: server/buffer/callback, `mqttConnect`, `mqttLoop` в начале `loop()`.
3. `publishState` на `ARDUINO_COMMAND_STATE` + на (re)connect.
4. LWT-топик `BASE/lwt`.
5. Удалить `sendMessageToIOT` и Yandex-TLS-обвес; `co2` пока публикуем как 0.
**Критерий:** в диагностике/панели Dealgate видны актуальные t/h/почва; в Алисе
«какая температура/влажность» озвучивает последние значения. Telegram/OTA/Gyver не сломаны.

### Этап 2. ESP: команды (задача 2)
1. `mqttCallback`: парсинг `power`/`vol`/`check`/`daily`, вызов `serialCommandWater`/`serialLog`.
2. Подписки в `mqttConnect` на `BASE/p/+/power`, `BASE/p/+/vol`, `BASE/cmd/+`.
   (PubSubClient поддерживает wildcard `+`.)
3. Проверить в приложении: тумблер → полив на `dailyAmountMl`; регулятор объёма →
   полив ровно X мл (видеть по расходу/Telegram).
4. Проверить голосом фразы для `volume` («установи объём полива … на 25 миллилитров»).
   Если не работает голосом — оставить как приложение + on/off голосом.
**Критерий:** обе исходные задачи работают: «полей цветок N» (голос) и
«полей 25 мл растение 2» (приложение, голос — по результатам проверки).

### Этап 3. CO₂ (когда появится датчик)
1. Mega: чтение датчика → `global_state.co2`.
2. `State.h`: `co2` в serialize/deserialize (если не добавили в Этапе 1), bump `EEPROM_VERSION`.
3. Dealgate: датчик CO₂ на JSON key `co2` (instance УДЯ `co2_level`, ppm).
**Критерий:** CO₂ виден в Алисе и истории.

### Этап 4. Краевые случаи и стабильность
- Reconnect при обрывах Wi-Fi/брокера (PubSubClient сам не реконнектит — `mqttLoop`).
- LWT корректно переключает статус «не в сети» в кабинете.
- Защита от частых публикаций (не чаще, чем приходит state от Mega; лимит 300/мин не бьём).
- Что если клапан не отвечает — статус в Telegram (уже есть `checkValveConnected`).
- «Полить всё» — сценарий Dealgate (опционально) или отдельная команда.
- Тест длительной работы (ночь) на утечки/reconnect.

## Риски и открытые вопросы

| Риск/вопрос | Статус | Mitigation |
|---|---|---|
| **Retained у Dealgate не подтверждён** | проверить на Этапе 0/1 | публиковать по таймеру 1–5 мин; либо RPC-топик `BASE/rq/state`, на который ESP отвечает публикацией |
| **Голосом задать `volume` (мл)** | проверить на Этапе 2 | если нет — регулятор только из приложения, голосом on/off; запасной вариант — `mode`-пресеты |
| **Лимит устройств Алисы/Dealgate** (16 кранов × 2 умения + датчики) | уточнить в `@dealgate_ru` | MVP: 3–4 ключевых растения в Алисе, все 16 — в Telegram |
| **Глобальное пространство топиков** | факт (дока) | уникальный `BASE` префикс |
| **PubSubClient max packet 256 байт** | факт | `setBufferSize(1024)` |
| **MQTT-loop голодает из-за задержек** (Telegram `getUpdates` и т.п.) | факт | `mqttLoop()` первой строкой `loop()`; longPoll у Telegram выключен |
| **CO₂-датчик ещё не выбран** | вне MVP | Этап 3, поле в `State` зарезервировать заранее |

## Чек-лист приёмки (MVP)
- [ ] ESP подключается к `mqtt.dealgate.ru`, статус online в кабинете, LWT = OFF при отключении.
- [ ] Температура/влажность воздуха актуальны в Алисе и на графике Dealgate.
- [ ] Влажность почвы (выбранные растения) видна в Алисе/кабинете.
- [ ] «Алиса, полей цветок N» → полив на `dailyAmountMl`, подтверждение в Telegram.
- [ ] Из приложения Алисы «объём = 25» для растения 2 → полив ровно 25 мл.
- [ ] «Проверить клапаны» и «дневной полив» работают из Алисы.
- [ ] Telegram-бот, OTA, Gyver не регрессировали.
- [ ] Тест ночного цикла: reconnect, нет утечек, статус online стабилен.

## Источники
- [Dealgate: MQTT сервер](https://dealgate.ru/help/4.html)
- [Dealgate: Настройка устройств](https://dealgate.ru/help/5.html)
- [Dealgate: JSON формат](https://dealgate.ru/help/15.html)
- [Dealgate: История/графики](https://dealgate.ru/help/10.html)
- [Dealgate: Сценарии](https://dealgate.ru/help/12.html)
- [Dealgate: FAQ](https://dealgate.ru/help/16.html)
- Предыдущее исследование: [`2026-05-26_yandex_alice_integration.md`](./2026-05-26_yandex_alice_integration.md)

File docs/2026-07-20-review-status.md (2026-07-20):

# Статус работ по ревью (Fable + GLM, 2026-07-19)

Сводная таблица по [2026-07-19-fable-review.md](2026-07-19-fable-review.md) и
[2026-07-19-glm-review.md](2026-07-19-glm-review.md). Нумерация — из синтез-саммари.

Статусы: `в работу` / `сделано` / `не важно` / `вопрос` (ждёт пояснения/решения) /
`обсудить` / `отдельная задача`.

## Критично

| № | Что | Решение Олега | Статус |
|---|-----|---|---|
| 1 | Валидация `plantId` на Mega (OOB-запись, случайный клапан) | согласен | сделано |
| 2 | Cap объёма полива | лимит **200 мл** | сделано |
| 3 | Whitelist chat id в Telegram | хардкод-массив разрешённых chatId + флаг отключения защиты | сделано |

## Надёжность

| № | Что | Решение Олега | Статус |
|---|-----|---|---|
| 4 | `wdt_reset` в циклах чтения чанков | ок | сделано |
| 5 | Починить `timeOut()` (STATE_TIMEOUT vs COMMUNICATION_TIME_OUT) | ок | сделано |
| 6 | `/daily`, `/checkvalves` из-под `#ifdef DEBUG_LOG` | не важно | не важно |
| 7 | Таймаут ручного полива по кнопке | не важно | не важно |
| 8 | Входящая очередь Communication = 2 | не важно | не важно |
| 9 | Блокирующие хендлеры команд в `loop()` | не важно | не важно |
| 10 | Bounds-check в `deserializeState` (ESP) | не важно | не важно |

## Функциональные баги

| № | Что | Решение Олега | Статус |
|---|-----|---|---|
| 11 | `normalizeDate` по значению | не важно | не важно |
| 12 | SD-индикатор экрана всегда зелёный | не важно | не важно |
| 13 | Дырки в графиках усредняются как 1022 | не важно | не важно |
| 14 | Медиана смещена на элемент | ок | сделано |
| 15 | Повторный попап не показывается | ок | сделано |
| 16 | `pompIsOn` не триггерит обновление стейта | ок | сделано |
| 17 | Таймзона: везде UTC + табуляция в NTP-хосте | ок | сделано |
| 18 | Висячий указатель на клиентский сертификат (Yandex IoT) | удалить IoT-код | отдельная задача |

## Эффективность

| № | Что | Решение Олега | Статус |
|---|-----|---|---|
| 19 | Замкнуть дозирование на расходомер | не делаем: система нестабильна, расходомер не откалиброван; он остаётся контролем «всё прошло успешно» | не важно |
| 20 | SD: держать LOG.txt открытым | ок | сделано |
| 21 | `String` → `snprintf` в горячих местах | давай | сделано |
| 22 | `State`/`Plant` по ссылке | ок | сделано |
| 23 | Двойной `analogRead` после переключения mux | ок, с комментарием в коде почему | сделано |
| 24 | Перерисовка экрана без мигания | давай | сделано |
| 25 | Реже дёргать `logFreeRam` | всё устраивает | не важно |

## Архитектура и гигиена

| № | Что | Решение Олега | Статус |
|---|-----|---|---|
| 26 | Include guard'ы + `inline`/вынос в .cpp | ок | сделано |
| 27 | `DEBUG_LOG` → build-flag в platformio.ini | ок | сделано |
| 28 | `SPI_DRIVER_SELECT=2` через build_flags | пробуем; методика тестирования — ниже | сделано |
| 29 | Разбить `Pomp` (Valves / FlowMeter / CurrentSensor) | ок | сделано |
| 30 | Общий парсер `/water` и `/config` | ок | сделано |
| 31 | Упростить UART-протокол (NDJSON+CRC) | обсудить отдельно | обсудить |
| 32 | Мёртвый код (`runNextDayTask`, `DATA_CHUNK_SIZE`, …) | пометить `// todo удалить` | сделано |
| 33 | Страховка `EEPROM_VERSION` через `sizeof(State)` | ок | сделано |
| 34 | Убрать VLA в `Graph::plot` | ок | сделано |
| 35 | Тесты (парсер команд, roundtrip стейта, очереди) | ок | сделано |
| 36 | `/graphs` по одному графику на сообщение | ок | сделано |

## Методика тестирования п.28 (SPI_DRIVER_SELECT через build_flags)

Проблема прошлых попыток скорее всего в том, что руками правленный
`SdFatConfig.h` уже лежал в `.pio/libdeps` и перебивал флаг, либо флаг
добавлялся не в то окружение. Порядок проверки:

1. **Чистая библиотека**: удалить `.pio/libdeps/megaatmega2560/SdFat`
   (или весь `.pio/libdeps/megaatmega2560`), чтобы PlatformIO скачал
   нетронутый SdFat — иначе тест ничего не докажет.
2. В `[env:megaatmega2560]` добавить `build_flags = -D SPI_DRIVER_SELECT=2`.
3. **Проверка на компиляции**: `SdFatConfig.h` оборачивает дефолт в
   `#ifndef SPI_DRIVER_SELECT` — значит внешний `-D` должен подхватиться.
   Убедиться: `pio run -e megaatmega2560 -v | grep SPI_DRIVER_SELECT` —
   флаг присутствует в командах компиляции; сборка без ошибок про
   `SoftSpiDriver` (класс существует только при SPI_DRIVER_SELECT=2,
   т.е. если бы флаг не подхватился — `AwLogging.h` просто не собрался бы).
4. **Проверка на железе**: прошить, смотреть Serial на boot:
   должно быть `SD is inited.` (а не `sd.initErrorPrint`). Дальше дождаться
   пары записей и проверить LOG.txt на карте с компа.
5. Если ок — убрать упоминание ручной правки из readme (шаг 1 в
   «Обязательные шаги перед сборкой»).

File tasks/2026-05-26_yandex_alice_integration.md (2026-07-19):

# Управление автополивом через Алису

Дата: 2026-05-26

## Цель

Голосом через Алису:
- «Алиса, полей цветок 5» → запуск полива растения 5 на заранее настроенный (`Plant::dailyAmountMl`) объём.
- «Алиса, проверь клапаны» → `checkAllActiveValves`, результат озвучивается / приходит в Telegram.
- «Алиса, какая влажность у цветка 3?» → значение последнего замера `originalValue`.

## Ограничения (заданы заказчиком)

- **Нет белого IP** (NAT провайдера).
- **Нет своего сервера / VPS / Home Assistant.** Бесплатные/дешёвые cloud-сервисы допустимы.
- **TLS/шифрование НЕ требуется** — заказчик: в домашней MQTT ничего секретного не летит. Это снимает разницу между брокерами по части TLS и **упрощает ESP-код** (обычный `WiFiClient` вместо `WiFiClientSecure`/BearSSL → экономия ~16-22 КБ RAM на ESP8266 + нет зависимости TLS от точности NTP).
- Aqara Hub M2 в той же сети — для DIY-мостов через неё путей не найдено. **Не используем.**

## ⚠️ Yandex IoT Core закрывается — архитектура изменена

Изначально план строился на Yandex IoT Core как MQTT-брокере. Но он закрывается
([sunset](https://yandex.cloud/ru/docs/iot-core/sunset)):
- **27.04.2026** — прекращены новые продажи (т.е. уже).
- **01.11.2026** — read-only.
- **01.12.2026** — полное отключение.
- Бэкапы (устройства, сертификаты) — до 31.01.2027 через техподдержку.
- Официальной замены Яндекс не предложил.

**Вывод:** IoT Core как брокер вычёркиваем. Берём сторонний российский MQTT-брокер
со встроенным навыком Алисы — это заодно убирает необходимость в своей Cloud Function.

## Выбор брокера (исследование 2026-05-26)

Оба основных кандидата — российские, MQTT 3.1.1 (совместимо с `PubSubClient`), со **встроенным навыком Алисы** (своя Cloud Function не нужна).

| Критерий | **Dealgate.ru** | WQTT.ru |
|---|---|---|
| Датчики (темп./влажн.) | ✅ тип «Датчики» в доке | ✅ подтверждено |
| range / mode (диммер/пресеты) | ✅ **оба в доке** | ⚠️ не подтверждено |
| on/off + сценарий, объём в прошивке | ✅ + Telegram-уведомления | ✅ |
| Порт / TLS | 1883 без TLS (нам ок) | TLS 8883 |
| **Цена** | ❓ нигде не опубликована | ~299₽/год (1 мес free) |
| Лимит устройств | ❓ не указан (брокер до 10k конн.) | «искусственно не ограничено» |

Отсеяны: **flespi** (геориск, оплата из РФ под вопросом), **HiveMQ/EMQX Cloud** (из РФ не оплатить). Запасной путь — **Mosquitto на VPS** (Timeweb/Selectel ~200-300₽/мес) + свой навык по шаблону [popstas/yandex-dialogs-smarthome-mqtt](https://github.com/popstas/yandex-dialogs-smarthome-mqtt), если упрёмся в каталоги обоих managed-брокеров.

**РЕШЕНИЕ: выбран Dealgate.ru.** Зарегистрировались (вход через Яндекс-логин), прайса/платёжных форм/лимитов в кабинете нет — сервис де-факто бесплатный (Telegram-канал — техподдержка, не продажи). Функционально впереди WQTT: датчики + range + mode + Telegram-уведомления задокументированы.

### Параметры подключения Dealgate (для этапа 1)

- **Host:** `mqtt.dealgate.ru`
- **Port:** из профиля (пример 1883), без TLS
- **Username / Password:** латиница + `_@`, задаются в профиле
- **ClientID:** обязателен и уникален; зарезервированы `dashboard`, `yandex`, `scenario`
- **Протокол:** MQTT 3.1, 3.1.1, 5.0 → `PubSubClient` (3.1.1) подходит
- **Топики:** не навязаны протоколом — **задаются вручную при настройке устройства в кабинете** (для тумблера: топик + payload для ON и для OFF; для датчика: топик чтения). Это гибко — формат придумываем сами.
- **Лимиты:** 300 публикаций/мин на соединение, до 10 000 соединений на порт, 6 неудачных авторизаций/мин — нам с большим запасом.
- **Retained:** в доке явно не упомянут — **проверить опытно** на этапе 1 (нужен, чтобы stateless-навык Алисы читал последнее состояние).

## Новая архитектура (вариант A — Dealgate/WQTT, без своего навыка)

```
[Алиса]
   │ voice
   ▼
[Встроенный навык брокера (Dealgate/WQTT) в «Доме с Алисой»]
   │ внутренняя кухня брокера
   ▼
[MQTT-брокер Dealgate/WQTT]   (1883 без TLS — нам ок; retained)
   │ MQTT 3.1.1
   ▼
[ESP8266]  (PubSubClient поверх обычного WiFiClient)
   │ UART JSON (уже есть)
   ▼
[Arduino Mega 2560]
   │ shift-регистры, помпа, клапаны
```

- **Команды Алисы → устройство:** Алиса дёргает «розетку/датчик» в кабинете брокера → брокер публикует в командный топик → ESP (подписан) получает, маппит на `ESP_COMMAND_*`, шлёт в Mega по UART.
- **Состояние устройства → Алиса:** ESP публикует состояние в **retained**-топики → брокер отдаёт Алисе при query.
- **Cloud Function НЕ нужна.** Маппинг устройств делается в кабинете брокера.
- Telegram-канал остаётся параллельно — не трогаем.

Резервная **архитектура B** (если каталоги обоих managed-брокеров окажутся тесными): Mosquitto на VPS + своя Cloud Function (навык УДЯ) по шаблону popstas. У VPS свой белый IP, ESP коннектится исходящим — NAT не мешает. Дороже (~2.5-3.6к₽/год) и требует писать навык.

## Схема маппинга устройства в Алису

По исследованию протокола УДЯ (типы/capabilities) и каталогов брокеров:

| Наша сущность | Представление в Алисе | Команда/запрос |
|---|---|---|
| 16 поливалок | 16 устройств тип **«Кран»** (есть в каталоге Dealgate) `on_off` «Полив цветка N» | «Алиса, полей пятый» (сценарий → ON крана 5) |
| Температура воздуха | датчик `float/temperature` | «Алиса, какая температура» |
| Влажность воздуха | датчик `float/humidity` | «Алиса, какая влажность» |
| Влажность почвы (по растению) | датчики `float/humidity`, имя «влажность почвы цветок N» | «Алиса, влажность почвы цветка 3» |
| Проверка клапанов | «розетка»/кнопка-сценарий → `ESP_COMMAND_CHECK_VALVES` | результат в Telegram |
| Дневной полив | кнопка-сценарий → `ESP_COMMAND_DAILY_TASK` | — |

**Ограничения, заложенные в схему:**
- **«Полить N мл» голосом — невозможно** (в УДЯ `range` имеет только 6 instance: `brightness/channel/humidity/open/temperature/volume`; миллилитров и кастомных единиц нет). Объём остаётся `dailyAmountMl` в прошивке, голос только триггерит полив. Произвольный объём — через Telegram-бот.
- **Отдельного instance «влажность почвы» нет** — используем `humidity`, различаем по имени устройства. Алиса семантически не отличит от влажности воздуха, но значение озвучит.
- Если 16 датчиков почвы раздувают аккаунт/лимит — вывести в Алису 2-3 ключевых, остальное смотреть в Telegram.
- Опционально: вместо чистого on/off попробовать `mode`-пресеты объёма («мало/средне/много») — **Dealgate поддерживает `mode` по доке**, WQTT — под вопросом. Это даст голосом «полей пятый по чуть-чуть». Не критично для MVP.

## Что уже сделано (обнаружено при ревизии кода)

1. **TLS-клиент на ESP работает** — [`EspMain.cpp:setupWifiClient`](../src/EspMain.cpp#L186): `BearSSL::X509List` + `BearSSL::PrivateKey`, `setClientRSACert`. **Но** сертификаты выпущены под Yandex IoT Core и под новый брокер не годятся. А раз TLS не требуется — **весь этот TLS-обвес выкидываем**: переходим на обычный `WiFiClient`, аутентификация через username/password брокера. Это упрощает код и экономит RAM. Из `SecretHolder` Yandex-сертификаты можно убрать.
2. **NTP** ([`EspMain.cpp:setup`](../src/EspMain.cpp#L407)) — нужен для TLS, остаётся.
3. **OTA** ([`setupOTA`](../src/EspMain.cpp#L230)) — остаётся.
4. **Telegram-бот** ([`loopTelegram`](../src/EspMain.cpp#L360)) с командами `/water`, `/config`, `/daily`, `/checkvalves`, `/state`, `/graphs` — остаётся как параллельный канал.
5. **UART-протокол ESP↔Mega** ([`Communication.cpp`](../src/Communication.cpp), типы в [`State.h`](../src/State.h)) — все нужные команды есть (`ESP_COMMAND_WATER_PLANT`, `ESP_COMMAND_CHECK_VALVES`, `ESP_COMMAND_DAILY_TASK`).
6. **PubSubClient (MQTT) в lib_deps ESP** ([`platformio.ini:57`](../platformio.ini#L57)) — готов, не используется.

## Что НЕ сделано / переделать

1. **`sendMessageToIOT`** ([`EspMain.cpp:470`](../src/EspMain.cpp#L470)) — HTTPS-REST к IoT Core, отключён заглушкой `if (true) return;`. **Удалить** — путь мёртвый (IoT Core закрывается).
2. **Нет MQTT-клиента** в `EspMain.cpp`.
3. **Нет аккаунта/брокера** на Dealgate/WQTT, нет привязки навыка к Алисе.
4. `setupWifiClient` + Yandex-сертификаты в `SecretHolder` — **удалить**, перейти на `WiFiClient` + username/password брокера в `SecretHolder`.

## План работ

### Этап 0. Выбор и регистрация на брокере (не код)

- **Написать в `@dealgate_ru`**: бесплатен ли сервис, лимиты, потолок устройств на аккаунт (нужно ~35). По ответу выбрать Dealgate (если ок) или WQTT (запасной, ~299₽/год).
- Завести аккаунт (Dealgate — вход через Яндекс-логин; WQTT — free-месяц), создать MQTT-логин (username/password).
- Узнать endpoint/порт и **схему топиков для навыка Алисы** (у каждого брокера свой формат — изучить их доку: где command-топик, где state, нужен ли retained явно).
- Создать в кабинете устройства по «Схеме маппинга» (16 розеток-поливалок + датчики + кнопки-сценарии).
- Привязать навык брокера в «Доме с Алисой», убедиться что устройства видны.

**Критерий:** в Алисе видны устройства, переключение в приложении меняет состояние в кабинете брокера (пока без железа).

### Этап 1. MQTT-клиент на ESP

- В `EspMain.cpp` поднять `PubSubClient` поверх обычного `WiFiClient` (без TLS).
- Подключиться к брокеру (endpoint/username/password из `SecretHolder`).
- Подписаться на командные топики (формат брокера).
- В callback: парсить, маппить на `ESP_COMMAND_*`, слать в Mega через существующие `serialCommandWater` / `serialLog` (как в [`procesTelegramMessage`](../src/EspMain.cpp#L286)).
- Публиковать состояние в **retained**-топики при получении `ARDUINO_COMMAND_STATE` от Mega (состояние поливалок + значения датчиков темп/влажность/почва).
- Reconnect-логика (PubSubClient сам не реконнектит).
- Удалить мёртвый `sendMessageToIOT` и `setupWifiClient` с TLS-обвесом.

**Критерий:** переключение «розетки» в приложении Алисы → ESP получает команду → Mega открывает клапан. Обратно: статус клапана и значения датчиков видны в кабинете брокера/Алисе.

### Этап 2. Маппинг команд и UX

- «Полей цветок N» = ON «розетки» N → полив на `dailyAmountMl`. (Произвольный объём через стандартную «розетку» не задать.)
- «Проверить клапаны» — отдельная «кнопка»/сценарий → `ESP_COMMAND_CHECK_VALVES`, результат в Telegram (Алиса голосом ответит лишь «выполнено»).
- «Дневной полив» — кнопка → `ESP_COMMAND_DAILY_TASK`.
- Влажность как сенсор — если каталог WQTT позволяет тип «датчик влажности», публиковать `originalValue`.

**Критерий:** все три голосовые команды из «Цели» работают.

### Этап 3. Крайние случаи

- Offline-детект: брокерный last-will/`online`-retained-топик → в кабинете WQTT статус «не в сети».
- Что если клапан не отвечает — статус в Telegram (уже есть `checkValveConnected`).
- Группа «полить всё» — средствами Алисы.

## Открытые вопросы

Закрыто исследованием:
- ✅ Типы устройств: оба брокера умеют датчики (`float`) и исполнительные устройства. Dealgate + `range`/`mode` по доке.
- ✅ Влажность почвы: через `humidity` instance, различаем по имени.
- ✅ «N мл» голосом: невозможно (ограничение УДЯ), объём в прошивке.

Закрыто на этапе 0:
- ✅ Брокер выбран — Dealgate, бесплатен де-факто.
- ✅ Параметры подключения и типы устройств известны (см. выше). Клапаны → тип «Кран».
- ✅ Топики задаются вручную в кабинете — формат придумываем сами.

Осталось:
1. **Retained у Dealgate** — проверить опытно на этапе 1 (нужен для query Алисы). Если нет — состояние придётся отдавать иначе (узнать у техподдержки).
2. **Произвольный объём** — для MVP фикс `dailyAmountMl` через on/off. Опционально позже — `mode`-пресеты «мало/средне/много» (Dealgate поддерживает `mode`).

## Источники

- [Yandex IoT Core — sunset](https://yandex.cloud/ru/docs/iot-core/sunset)
- [popstas/yandex-dialogs-smarthome-mqtt](https://github.com/popstas/yandex-dialogs-smarthome-mqtt) — шаблон своего навыка УДЯ поверх произвольного MQTT (для архитектуры B).
- [alexstar.ru: голосовое управление умным домом по MQTT](https://alexstar.ru/web/smarthome/alice-vcliuchi-svet-golosovoe-gupravlenie-umnym-domom-po-mqtt-protokolu)
- WQTT.ru / Dealgate.ru — кабинеты и доки по навыку Алисы (изучить на этапе 0).

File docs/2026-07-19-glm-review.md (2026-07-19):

# Ревью проекта — 2026-07-19 (glm-5.2)

Самостоятельный разбор всего `src/` (прошивки Mega2560 и ESP8266). Косметика отфильтрована.
Там, где находка совпадает с уже существующим `docs/2026-07-19-fable-review.md`, помечаю
**[подтверждено]** и при необходимости уточняю; **[новое]** — то, что в прошлом ревью не всплыло.
Пара мест проверена препроцессором/g++, чтобы не гадать.

---

## 1. Архитектура, модульность

### 1.1. Заголовки без include guard + глобальные объекты в `.h` **[подтверждено]**
`Pomp.h`, `Screen.h`, `Sensors.h`, `Graph.h`, `AwClock.h` — без `#ifndef` guard'ов.
В `State.h` guard есть, но там же лежат **non-inline** свободные функции
(`dateToString`, `serializeState`, `deserializeState`, …). Всё это собирается
только потому, что каждый `.h` включается ровно в одну единицу трансляции; любой
второй include → ODR/multiple-definition. Минимум — guard'ы + `inline`; правильно —
определения в `.cpp`. Самая «архитектурная» хрупкость проекта.

### 1.2. `DEBUG_LOG` живёт в `Communication.h` и рулит всем проектом **[подтверждено]**
`#define DEBUG_LOG` в [Communication.h:9](src/Communication.h#L9) включает логи в обеих
прошивках. Связка неочевидна (см. ещё 3.9 — там она ломает функциональность).
`DEBUG_LOG` должен быть build-flag в `platformio.ini`, а не сидеть внутри чужого хедера.

### 1.3. `Pomp` — класс-«мусоросборник» **[подтверждено]**
Один класс отвечает за насос, клапаны (74HC595), кнопки (CD74HC4067), расходомер и
ACS712 — пять независимых устройств. Симптом: вызывающий код вынужден «прошивать»
порядок вызовов через публичные `beginWateringAmpStats` / `sampleWateringAmpIfNeeded` /
`loopFlowSensor` / `beforeLoopFlowSensor`. Разбить на `Valves`, `FlowMeter`,
`CurrentSensor` — и код, и native-тесты стали бы сильно проще (сейчас покрыт только `Graph`).

### 1.4. Мёртвый планировщик `runNextDayTask` / `State::nextTaskRuning` **[подтверждено]**
Не вызывается нигде, но `nextTaskRuning` сохраняется в EEPROM (с мусором). Либо
доделать (см. баг 3.4), либо убрать до реализации.

### 1.5. Дубликаты `serialCommandWater`/`serialConfig` и парсеров `/water`/`/config` **[подтверждено]**
Две идентичные функции (отличаются константой команды) + два парсера с magic-смещениями
`substring(12,…)` / `substring(13,…)`, завязанными на длину слова. Один общий
парсер `<cmd> plantX Yml` убирает и дубль, и смещения.

### 1.6. Ручная правка `SdFat` вместо build-flag **[подтверждено]**
Шаг «поставить `SPI_DRIVER_SELECT = 2` в исходниках библиотеки» теряется при
переустановке. Достаточно `build_flags = -D SPI_DRIVER_SELECT=2` в mega-окружении.

### 1.7. Команды исполняются синхронно в `loop()` — связь умирает на время полива **[новое]**
`processEspCommand` для `esp_daily` крутит `runDailyCommand()` (полив всех активных
растений подряд), а для `esp_water` — один длинный полив. Всё это внутри обработки
одного UART-сообщения: `loop()` не возвращается в `communicationTick` минуты.
Входящий буфер UART тем временем переполняется, chunk-протокол на стороне ESP
таймаутится, входящие команды/синхронизация времени теряются. Сейчас «прокатывает»
только потому, что полив короткий и по одной команде за раз. Это и архитектурный
запах (хендлер команды = блокирующая процедура в loop), и корень нескольких багов
из блока 3.

---

## 2. Эффективность решений

### 2.1. Open-loop дозирование при наличии рабочего расходомера **[подтверждено]**
`waterPlant` ([Pomp.h](src/Pomp.h)) отмеряет объём через `practicalSpeedMlInMs = 0.0077`,
а показания YF-S401 идут только в отчёт. Константа захардкожена, без калибровки и
зависит от напора/трубок/конкретного клапана. Контур уже есть — лить до набора
запрошенных мл по датчику, с таймаутом по времени как аварийным пределом.
Бонусом: бесплатная диагностика «вода не течёт» (нет пульсов при работающем насосе).

### 2.2. `String`-арифметика на AVR с 8 КБ RAM **[подтверждено]**
Отчёты/JSON собираются конкатенацией `String` — десятки heap-реаллокаций за полив.
Мониторинг `freeRam` и комментарий «оборачивать в F нельзя, виснет» — симптомы той
же фрагментации. Для горячих мест надёжнее `snprintf` в статический буфер
(как уже сделано в `logFreeRam`).

### 2.3. `State`/`Plant` копируются по значению **[подтверждено]**
`serializeState(State)`, `deserializeState(...)`, `isDefined(Plant)`, `dateToString(...)`,
плюс `lastState = state` на ESP. State — ~300 байт, на стеке Mega это ощущается.
Передавать `const State&` / `const Plant&`.

### 2.4. Блокирующий chunk+ack по UART с polling-delay **[подтверждено]**
Каждые 62 байта требуют round-trip `next`, `readNextChunk` опрашивает порт с
`delay(10)` (до 5 c на чанк). Для двух чипов на одной плате (канал без потерь)
это самая сложная и хрупкая часть системы. Хватило бы newline-delimited JSON + CRC
с неблокирующим чтением.

### 2.5. Полная перерисовка экрана **[подтверждено]**
`loopScreen` делает `fillScreen` + полный вывод при каждом обновлении стейта — мигание
и SPI-трафик. Дешёвая страховка: перерисовывать только изменившиеся строки.

### 2.6. Чтение мультиплексера без settle-задержки **[подтверждено]**
В `loopSoilMoistureSensors` `analogRead` идёт сразу после переключения канала
(`delay(50)` закомментирован). Ёмкостные датчики медленные, первый замер после
переключения может тащить заряд соседнего канала. Дешёво: двойной `analogRead`
(первый выкинуть), ~200 мкс вместо 50 мс.

### 2.7. SD-лог открывается/закрывается на каждую строку **[новое]**
`AwLogging::writeln` и `logFreeRam` делают `sd.open("LOG.txt", FILE_WRITE)` → запись →
`file.close()` на **каждый** вызов. При включённом `DEBUG_LOG` это десятки SD-write'ов
за один тик `loop()` — dominated by I/O, плюс усиленный износ карты (FAT-таблица
обновляется постоянно). Нужно держать файл открытым и flush'ить по таймеру/объёму.

### 2.8. `freeRam()` вызывается слишком часто и пишет на SD **[новое]**
`logFreeRam` дёргается до/после каждой операции и через (2.7) каждый раз уходит на SD.
На AVR ещё и сам замер heap не бесплатен. Логировать RAM разумнее периодически,
а не вокруг каждого действия.

---

## 3. Ошибки в логике, косяки

### 3.1. [Критично] Нет проверки границ `plantId` — порча памяти **[подтверждено, уточнено]**
`processEspCommand` ([sketch_auto_watering.ino:161](src/sketch_auto_watering.ino#L161))
берёт `id` из JSON без проверки. На ESP `isValidInteger` смотрит только «все символы —
цифры», поэтому `/config plant99 50ml` проходит валидацию, а на Mega выполняется
`global_state.plants[99].dailyAmountMl = amount` — запись ~1500 байт за пределы
массива, порча произвольной памяти, и тут же `saveStateEEPROM()` фиксирует мусор.
Для `/water plant99` дополнительно: `patchValveId(99)=102`, `bitWrite(currentState, 102, HIGH)`
= `1UL << 102` — сдвиг на ≥ ширины типа, UB; на практике на AVR может установить
произвольный бит, т.е. открыть **случайный** клапан при работающем насосе. Нужна
проверка `0 <= id < PLANTS_AMOUNT` на Mega (и желательно на ESP).

### 3.2. [Серьёзно] Объём полива не ограничен сверху **[подтверждено]**
`/water plant3 90000ml` — легальная команда, ~3 часа полива одного горшка. Опечатка
в Telegram (лишний ноль) → затопленный подоконник. Разумный cap (например 500 мл)
на стороне Mega.

### 3.3. [Серьёзно] WDT 8 c против блокирующего протокола **[подтверждено, дополнено]**
`readNextChunk` блокирует до 5 с (500 × `delay(10)`), а `readMessageAfterCommunicationStart`
крутит приём чанков **без `wdt_reset`** между ними. Два таймаута подряд внутри одного
`communicationTick` → загадочный ребут Mega именно при деградации связи. Та же
картина в отправке стейта в `communicationTick`: серия `readNextChunk` подряд без
сброса WDT. Лечится `wdt_reset()` в циклах чтения (или уменьшить `COMMUNICATION_TIME_OUT_CTN`).

### 3.4. `normalizeDate` принимает аргумент по значению — функция-пустышка **[подтверждено]**
[AwClock.h:68](src/AwClock.h#L68): все инкременты теряются на выходе. Дремлет, пока
не включен планировщик (1.4). Должно быть `Ds1302::DateTime&`.

### 3.5. SD-индикатор на экране всегда «хорошо» через `#ifdef` **[подтверждено, проверено]**
[Screen.h:75](src/Screen.h#L75):

```cpp
#ifdef SD_TURNED_OFF
  bool screenState = true;
#elif
  bool screenState = globalState.sdInited;
#endif
```

`SD_TURNED_OFF` определён как `false`, но `#ifdef` проверяет факт определения, а не
значение → ветка `true` берётся всегда. Проверил препроцессором g++: `#elif` без
выражения компилируется молча, но ветка мертва. Фон экрана не краснеет при отвале SD
(нижний статус-бар при этом отдельно рисует `SD` корректно — это и спасает). Достаточно
`bool screenState = globalState.sdInited;` без препроцессора.

### 3.6. [Серьёзно] `timeOut()` сравнивает не с тем — мёртвая ветка таймаута **[подтверждено, проверено]**
[Communication.h:57](src/Communication.h#L57): `if (state == COMMUNICATION_TIME_OUT)`,
где `COMMUNICATION_TIME_OUT = 10` (длительность delay). А `readNextChunk` при таймауте
ставит `state = STATE_TIMEOUT` (= 5). Проверил: 5 ≠ 10 → `timeOut()` **всегда false**,
все `if (timeOut(ret)) return;` — мёртвый код. После таймаута исполнение идёт дальше
парсить мусорный `ret` и падает в `STATE_FAILED`. Итог похожий (восстановление через
hellow-world), но: в логе врёт диагностика («unexpected message» вместо «timeout»), и
чистый путь восстановления по таймауту не работает вообще. Должно быть
`state == STATE_TIMEOUT`.

### 3.7. Дырки в графике усредняются как `1022` **[подтверждено]**
`getGrapghString` не передаёт в `Graph` точки со значением `UNDEFINED_PLANT_VALUE`, но
конструктор инициализирует весь массив именно этим значением, а `plot()` усредняет бины
без проверки. Пропуски в истории → ложные пики и растянутая шкала Y. В `plot()` надо
пропускать undefined при усреднении (бин без данных рисовать пробелом).

### 3.8. Медиана смещена на элемент **[подтверждено]**
`getMedian`: `_graphs[start + _ids/2 + (_ids%2)]`. Для 7 элементов даёт индекс 4
вместо 3, для 3 — индекс 2 вместо 1. Фильтр работает, но систематически берёт значение
выше медианы. Правильно: `start + _ids/2`.

### 3.9. `/daily` и `/checkvalves` перестают работать без `DEBUG_LOG` **[подтверждено, проверено]**
На ESP команды пересылаются в Mega через `serialLog(ESP_COMMAND_DAILY_TASK, …)` и
`serialLog(ESP_COMMAND_CHECK_VALVES, …)` ([EspMain.cpp:311,316](src/EspMain.cpp#L311)),
а всё тело `serialLog` обёрнуто в `#ifdef DEBUG_LOG`. Убери кто-нибудь `#define DEBUG_LOG`
— и две **боевые** команды молча исчезнут. Функциональную отправку команд надо вынести
в отдельную функцию, не зависящую от логирования.

### 3.10. Повторный попап с тем же текстом не показывается **[подтверждено]**
`drawScreenMessage` дедуплицирует по `lastMessage`, но `loopScreen` этот флаг не
сбрасывает. Два нажатия «проверка клапанов» с одинаковым результатом подряд → второй
попап не отрисуется. Сбрасывать `lastMessage` в `loopScreen`.

### 3.11. Смена `pompIsOn` не триггерит обновление стейта **[подтверждено, дополнено]**
`updatePlantsState` меняет `state.pompIsOn`, но `wasUpdate` выставляется только по
тумблерам растений. Переключение тумблера насоса не вызовет `stateUpdated()`,
`saveStateEEPROM()` и `loopScreen()` — индикатор `pomp` на экране обновится лишь при
следующем чужом обновлении.

### 3.12. RTC хранит/отдаёт UTC, а не местное время **[подтверждено, проверено]**
`configTime("UTC+3", …)` (знак в POSIX инвертирован, для Москвы надо `MSK-3`), и при
этом `getTimestamp()` + `serialTimeSynced()` используют `gmtime_r` → в Mega и в
Telegram уходит чистый UTC. Экран и подписи отчётов врут на 3 часа. Дополнительно:
в строке NTP-сервера литеральная табуляция внутри имени хоста
(`"ntp6.ntp-servers.net\t"`) — этот сервер не резолвится. Лечится `MSK-3` + `localtime_r`.

### 3.13. Висячий указатель на клиентский сертификат (дремлет) **[подтверждено]**
[EspMain.cpp:194](src/EspMain.cpp#L194): `BearSSL::X509List x509(publicCert().c_str())`
— локальная переменная, `setClientRSACert(&x509, privKey)` хранит указатель; после
выхода — висячий, `privKey` (`new`) утёк. Пока IoT отключён (`if (true) return;`),
не стреляет. Оба объекта должны быть статическими/глобальными.

### 3.14. Тот же класс бага, что 3.1, на стороне ESP — нет проверки `id` **[новое]**
`deserializeState` ([State.h](src/State.h)) берёт `id` из JSON и пишет `out.plants[id]`
без проверки границ. Сейчас Arduino = доверенный отправитель, так что дремлет. Но это
та же дыра: при любом искажении протокола/фаззинге ESP падает или портит стек. Стоит
прикрыть симметрично с 3.1.

### 3.15. Ручной полив по кнопке без таймаута **[новое]**
В `loop()` цикл `while (pomp.isWaterNowButtonPressed(i))` крутится до отпускания кнопки.
Залипшая кнопка/пин → бесконечный полив (WDT при этом честно ресетится, так что ребута
не будет и никто не узнает). Авто-полив ограничен числом итераций, ручной — нет. Нужен
cap по времени как аварийный предел.

### 3.16. Входящая очередь сообщений всего из 2 элементов с тихой потерей **[новое]**
`COMMUNICATION_IN_MESSAGES_LENGTH = 2` ([Communication.h:21](src/Communication.h#L21)),
при переполнении молча перезатирается «первый». Любая короткая пачка входящих (пользователь
прожал две команды подряд + шедулер/ESP что-то прислал) → потеря команды без следа в логах.
Исходящая очередь (`OUT = 10`) чуть комфортнее, но там та же semantics тихой потери.
Минимум — увеличить `IN` и/или сигнализировать о дропах в лог.

---

## 4. Прочее

### 4.1. Безопасность Telegram-бота **[подтверждено, уточнено]**
`loopTelegram` принимает команды из **любого** чата и переключает `telegramChatId` на
последнего написавшего. Любой, кто найдёт бота по имени, получает управление поливом и
перехват отчётов. Уточнение по секретам:
- `telegramChatId = "-5065686553"` захардкожен в **трекаемом** `EspMain.cpp`;
- имя бота `@AquatoriaAutoWatering_bot` тоже в коде;
- `SecretHolder.cpp` (токен, wifi-пароль, сертификаты) **правильно** в `.gitignore` и
  в репозиторий не попал — это ОК. Но дефолтный chatId всё равно живёт в исходнике.
- `espClient.setInsecure()` отключает проверку сертификата Telegram — токен бота ходит
  через TLS без валидации сервера.

Минимум: whitelist chat id в `SecretHolder`, игнор всех прочих; не переназначать
`telegramChatId` автоматически.

### 4.2. Лимит Telegram 4096 на `/graphs` **[подтверждено]**
Один график ~500–600 символов; при 8+ активных растениях сообщение превысит лимит,
`sendMessage` молча вернёт false. Слать по графику на сообщение.

### 4.3. Мёртвый код и рассинхрон мелочей **[подтверждено]**
`DATA_CHUNK_SIZE` (дубль), `sendIotFrequencyInMinutes`, `updatedSettings` (выставляется,
не читается), `getBearerAuthKey` (возвращает пустой `secretKey`), `PIN_POMP_MAIN`
(всегда spare). `pinmap.md` ссылается на отсутствующий `backlog.md`.

### 4.4. Тесты **[подтверждено]**
Покрыт только `Graph` (native env, запуск через Docker из-за MSYS2). Самые выгодные
следующие кандидаты без железа: парсер Telegram-команд, `serializeState`/`deserializeState`
(roundtrip поймал бы 3.14), `normalizeDate` (поймал бы 3.4), логика очередей
`Communication` через стаб `Stream` (поймала бы 3.6 и 3.16).

### 4.5. VLA в `Graph::plot` **[новое]**
`int finalGraph[graphLength]` и `char out[graphHeight][graphLength]` — variable-length
arrays, расширение GCC, не стандарт C++. Сейчас размеры ограничены (≤40 и =10), но при
изменении констант легко поймать stack overflow без предупреждения (особенно на ESP).
Лучше `std::array`/статический буфер с `assert`-ом на размер, либо аллокация с проверкой.

### 4.6. Дисциплина `EEPROM_VERSION` **[новое]**
Коммент в `State.h`: «Изменил, обнови EEPROM_VERSION» (сейчас 5). В `State` есть
закомментированные поля/TODO. Забыл bumped → `loadStateEEPROM` грузит мусор, т.к.
`version == EEPROM_VERSION`, аlayout уже не совпал. Стоит либо статик-assert на
`sizeof(State)`, либо хранить размер рядом с version и проверять оба.

---

## Приоритеты

1. **3.1 + 3.2** — валидация `plantId` и cap объёма на Mega (удалённо триггеряемая порча
   памяти + потоп). Самое острое.
2. **3.6** — починить `timeOut()` (`STATE_TIMEOUT` вместо `COMMUNICATION_TIME_OUT`):
   мёртвая ветка восстановления по таймауту + врущая диагностика.
3. **3.3** — `wdt_reset` в циклах чтения чанков (загадочные ребуты при деградации связи).
4. **4.1** — whitelist chat id в Telegram (чужое управление поливом).
5. **3.9** — вынести пересылку команд из-под `#ifdef DEBUG_LOG` (боевые команды
   исчезают от одного `#define`).
6. **1.1 + 1.2** — include guard'ы + убрать `#define DEBUG_LOG` из `Communication.h`
   (фундамент для всего остального рефакторинга и тестов).
7. **2.1** — замкнуть дозирование на расходомер (точность + бесплатная диагностика).
8. **2.7** — держать LOG.txt открытым (нагрузка на SD и латенси loop).
9. **3.14 / 3.16 / 3.15** — прикрыть симметричные косяки (ESP-side id, очередь входящих,
   таймаут ручного полива).

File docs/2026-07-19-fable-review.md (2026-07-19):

# Ревью проекта — 2026-07-19 (Claude Fable 5)

Обзор всего кода `src/` (прошивки Mega2560 и ESP8266). Косметика отфильтрована,
ниже только то, что влияет на корректность, надёжность или сопровождаемость.

---

## 1. Архитектура, модульность

### 1.1. Общая оценка

Разделение обязанностей между Mega (железо, стейт, исполнение) и ESP (внешний мир)
здравое, `State.h` как общий контракт двух прошивок — правильное решение.
`Communication` выделен в отдельный класс с очередями — тоже хорошо. Основные
претензии ниже — про хрупкость сборки и размытые границы модулей.

### 1.2. Глобальные объекты в заголовках — хрупкость single-TU

`Screen.h` определяет глобальную `lcd`, `Pomp.h` — глобальную `flowSensor` и
free-функцию `waterFlowCount()`, `State.h` — несколько non-inline функций
(`dateToString`, `serializeState`, ...). Всё работает только потому, что каждый
заголовок включается ровно в одну единицу трансляции. Любой второй include —
ошибки линковки (ODR). Ни в одном из этих файлов нет include guard
(`Pomp.h`, `Screen.h`, `Sensors.h`, `AwClock.h`, `Graph.h`). Минимум — добавить
guard'ы и пометить функции `inline`; правильнее — вынести определения в .cpp.

### 1.3. `DEBUG_LOG` определён внутри Communication.h и управляет всем проектом

`#define DEBUG_LOG` живёт в [Communication.h:9](src/Communication.h:9) и включает
отладочное логирование во всех файлах обеих прошивок. Это неочевидная связка:
человек, выключающий «лог коммуникации», выключит логи везде. Хуже того — от него
зависит функциональность, см. пункт 3.9.

### 1.4. `Pomp` — слишком много обязанностей

Класс `Pomp` управляет насосами, клапанами (сдвиговые регистры), кнопками
(мультиплексер), датчиком расхода и датчиком тока — пять независимых устройств.
Это уже мешает: замер тока и flow-сенсор пришлось «прошивать» через публичные
методы (`beginWateringAmpStats` / `sampleWateringAmpIfNeeded` / `loopFlowSensor`),
которые вызывающий код обязан дёргать в правильном порядке. Разбиение на
`Valves`, `FlowMeter`, `CurrentSensor` упростило бы и код, и покрытие
native-тестами (сейчас тестами покрыт только `Graph`).

### 1.5. Мёртвый / нереализованный код планировщика

`AwClock::runNextDayTask` и `State::nextTaskRuning` не используются нигде
(автозапуск polива по расписанию так и не реализован, readme это честно
признаёт). При этом `nextTaskRuning` сохраняется в EEPROM и содержит мусор.
Либо доделать (там же баг 3.4), либо убрать до реализации.

### 1.6. Дублирование в EspMain

- `serialCommandWater()` и `serialConfig()` — идентичные функции, отличаются
  одной константой команды.
- Парсинг `/water` и `/config` — два почти одинаковых блока с magic-смещениями
  (`substring(12, ...)` / `substring(13, ...)`), завязанными на длину слова
  команды. Один общий парсер `<cmd> plantX Yml` убрал бы оба блока и смещения.

### 1.7. Ручная правка библиотеки SdFat вместо build-флага

Обязательный шаг «поменять `SPI_DRIVER_SELECT` в исходниках SdFat» (readme)
теряется при переустановке библиотеки. `SdFatConfig.h` уважает внешнее
определение — достаточно в `platformio.ini` для mega добавить
`build_flags = -D SPI_DRIVER_SELECT=2`, и шаг исчезает.

---

## 2. Эффективность решений

### 2.1. Дозирование полива — open-loop, хотя есть датчик расхода

`waterPlant()` ([Pomp.h:327](src/Pomp.h:327)) отмеряет объём по времени через
константу `practicalSpeedMlInMs = 0.0077`, а показания YF-S401 только
записываются в отчёт («Real ml = ...»). Датчик уже есть и работает — логично
замкнуть контур: лить до достижения запрошенных мл по датчику, с таймаутом по
времени как аварийным пределом. Это заодно даст бесплатную диагностику
«вода не течёт» (пульсов нет при работающем насосе).

### 2.2. String-арифметика на AVR с 8 КБ RAM

Отчёты, логи и JSON собираются конкатенацией `String` — десятки реаллокаций
на heap за один полив. Постоянный мониторинг `freeRam` в коде намекает, что
с фрагментацией уже боролись. Комментарий «оборачивать в F нельзя, виснет...»
([sketch_auto_watering.ino:174](src/sketch_auto_watering.ino:174)) — почти
наверняка следствие этой же фрагментации. Для горячих мест (отчёт о поливе,
конфиг-лист) надёжнее `snprintf` в статический буфер, как уже сделано в
`logFreeRam`.

### 2.3. Копирование State по значению

`serializeState(State state)`, `deserializeState(JsonDocument doc)`,
`isDefined(Plant plant)`, `dateToString(Ds1302::DateTime now)` — всё по
значению. `State` — это ~300+ байт (16 растений), копируется на стеке при
каждой отправке стейта. На Mega со свободными ~2-4 КБ это заметно. Передавать
`const State&` / `const Plant&`.

### 2.4. Протокол UART: chunk+ack с polling-задержками

Каждые 62 байта требуют round-trip подтверждения `next`, а `readNextChunk`
опрашивает порт с шагом `delay(10)`. Отправка стейта (~5-7 чанков) — это
десятки миллисекунд задержек чистого ожидания, и всё это время `loop()`
заблокирован (см. также 3.3). Для UART между двумя чипами на одной плате
(канал практически без потерь) хватило бы newline-delimited JSON + CRC с
неблокирующим чтением; текущий handshake-протокол — самая сложная и самая
хрупкая часть системы.

### 2.5. Полная перерисовка экрана

`loopScreen` делает `fillScreen` + полный вывод при каждом обновлении стейта
(раз в минуту по таймеру датчиков) — мигание и ~десятки мс SPI-трафика.
Достаточно перерисовывать изменившиеся строки (или хотя бы не заливать фон,
пока статус не изменился).

### 2.6. Чтение мультиплексера без settle-задержки

В `loopSoilMoistureSensors` `analogRead` идёт сразу после переключения каналов
CD74HC4067 (`delay(50)` закомментирован). У ADC AVR вход высокоомный, а
ёмкостные датчики медленные — первый замер после переключения может тащить
заряд предыдущего канала. Дешёвая страховка: двойной `analogRead` (первый
выбрасываем) — 200 мкс вместо 50 мс.

---

## 3. Ошибки в логике, косяки

### 3.1. [Серьёзно] Нет проверки границ plantId — порча памяти

`processEspCommand` ([sketch_auto_watering.ino:161-183](src/sketch_auto_watering.ino:161)):
`plantId` из JSON используется без проверки диапазона.
`/config plant99 50ml` пройдёт валидацию ESP (`isValidInteger` проверяет только
«все символы — цифры») и на Mega выполнит
`global_state.plants[99].dailyAmountMl = amount` — запись далеко за границей
массива, порча произвольной памяти + затем `saveStateEEPROM()` зафиксирует
испорченный стейт. `/water plant99` аналогично откроет несуществующий клапан
(бит 102 в 24-битном регистре — молча уйдёт в никуда, но полив запустится с
закрытыми клапанами → давление в магистрали). Нужна проверка
`0 <= id < PLANTS_AMOUNT` на Mega (и лучше ещё на ESP).

### 3.2. [Серьёзно] Объём полива не ограничен сверху

`/water plant3 90000ml` — легальная команда: ~3 часа непрерывного полива
одного горшка. Опечатка в Telegram (лишний ноль) → затопленный подоконник.
Нужен разумный cap (например 500 мл за команду) на стороне Mega.

### 3.3. WDT 8s против блокирующего протокола связи

`readNextChunk` блокирует до 5 с (500 × 10 мс) на каждый чанк, а приём
многочанкового сообщения в `readMessageAfterCommunicationStart` крутится без
`wdt_reset` между чанками. На хорошем канале всё быстро, но при деградации
связи (шум, зависший ESP посреди передачи) два подряд таймаута по 5 с внутри
одного `communicationTick` превышают 8-секундный WDT → «загадочные» ребуты
Mega именно в моменты проблем со связью. Добавить `wdt_reset()` в цикл чтения
чанков (или уменьшить `COMMUNICATION_TIME_OUT_CTN`).

### 3.4. `normalizeDate` принимает аргумент по значению — функция-пустышка

[AwClock.h:68](src/AwClock.h:68): `void normalizeDate(Ds1302::DateTime newDate)` —
все инкременты month/day теряются при выходе. Когда `runNextDayTask` включат,
31-е число + `day++` даст day=32, дата не нормализуется, и сравнение
`isNowAfter` сломается. Должно быть `Ds1302::DateTime&`. Сейчас дремлет,
т.к. планировщик не вызывается (см. 1.5).

### 3.5. Индикатор SD на экране всегда «хорошо»: битый препроцессор

[Screen.h:75-79](src/Screen.h:75):

```cpp
#ifdef SD_TURNED_OFF
  bool screenState = true;
#elif
  bool screenState = globalState.sdInited;
#endif
```

`SD_TURNED_OFF` определён как `false` в AwLogging.h — но `#ifdef` проверяет
факт определения, а не значение, поэтому ветка `true` берётся всегда, фон
экрана не краснеет при отвале SD. Плюс `#elif` без выражения (должен быть
`#else`). В AwLogging тот же макрос используется как runtime-значение
(`if (SD_TURNED_OFF)`) — два разных способа употребления одного флага.
Учитывая, что нижний статус-бар и так рисует отдельный индикатор `SD`,
проще всего: `bool screenState = globalState.sdInited;` без препроцессора.

### 3.6. `timeOut()` сравнивает state не с той константой

[Communication.h:57](src/Communication.h:57): `if (state == COMMUNICATION_TIME_OUT)` —
это константа `10` (длительность delay), а `readNextChunk` при таймауте ставит
`state = STATE_TIMEOUT` (= 5). Условие не срабатывает никогда: все `if (timeOut(ret)) return;`
мертвы, после таймаута код идёт дальше сравнивать мусорный `ret` с токенами и
валится в `STATE_FAILED`. Итог похожий (восстановление через hellow world), но
диагностика в логе врёт, а ветка таймаута — мёртвый код. Должно быть
`state == STATE_TIMEOUT`.

### 3.7. Дырки в данных графика усредняются как 1022

`getGrapghString` ([EspMain.cpp:274](src/EspMain.cpp:274)) не передаёт в `Graph`
точки со значением `UNDEFINED_PLANT_VALUE`, но конструктор `Graph` инициализирует
весь массив именно этим значением, а `plot()` усредняет бины без проверки на
undefined. Если у растения есть пропуски в истории (включили посреди окна,
датчик дал 1023), в соответствующие бины замешивается 1022 → ложные пики на
графике и растянутая шкала Y. В `plot()` нужно пропускать undefined-значения
при усреднении (и бин без данных рисовать пробелом).

### 3.8. Медиана смещена на элемент

`PointsHoler::getMedian` ([Graph.h:242](src/Graph.h:242)):
`_graphs[start + _ids/2 + (_ids%2)]` — для 7 элементов даёт индекс 4 (пятый),
а медиана — индекс 3. Для 3 элементов — индекс 2 вместо 1. Фильтр работает,
но систематически берёт значение выше медианы. Правильно: `start + _ids/2`.

### 3.9. `/daily` и `/checkvalves` перестанут работать без DEBUG_LOG

На ESP команды пересылаются в Mega через `serialLog(ESP_COMMAND_DAILY_TASK, ...)`
([EspMain.cpp:311](src/EspMain.cpp:311)) — а всё тело `serialLog` обёрнуто в
`#ifdef DEBUG_LOG`. Убери кто-нибудь `#define DEBUG_LOG` из Communication.h —
и две боевые команды молча исчезнут. Функциональную отправку команд нужно
делать отдельной функцией, не зависящей от логирования.

### 3.10. Повторный попап с тем же текстом не показывается

`drawScreenMessage` дедуплицирует по `lastMessage`, но между двумя вызовами
экран перерисовывает `loopScreen`. Сценарий: нажали кнопку проверки клапанов,
результат «Valve check OK: plant0 OK» показался; через минуту нажали ещё раз —
результат тот же, попап не отрисуется вовсе (только пищалки/телеграм).
`lastMessage` нужно сбрасывать в `loopScreen`.

### 3.11. Смена `pompIsOn` не триггерит обновление стейта

`updatePlantsState` ([Pomp.h:185](src/Pomp.h:185)) обновляет `state.pompIsOn`,
но `wasUpdate` выставляется только по тумблерам растений. Переключение тумблера
насоса не вызовет ни отправку стейта на ESP, ни перерисовку экрана — индикатор
`pomp` на экране обновится только со следующим чужим обновлением.

### 3.12. Таймзона: RTC хранит UTC, а не местное время

`configTime("UTC+3", ...)` — во-первых, в POSIX-нотации знак инвертирован
(«UTC+3» = UTC−3 местного), для Москвы нужно `"MSK-3"`; во-вторых, это неважно,
потому что и `getTimestamp()`, и `serialTimeSynced()` используют `gmtime_r` —
в Mega и на экран уезжает чистый UTC. Часы на экране и подписи логов врут на
3 часа. Если задумано локальное время — использовать `localtime_r` и починить
TZ-строку. Заодно: в списке NTP-серверов первая строка содержит табуляцию
внутри имени хоста (`"ntp6.ntp-servers.net\t"`) — этот сервер не резолвится.

### 3.13. Висячий указатель на клиентский сертификат (дремлет)

`setupWifiClient` ([EspMain.cpp:194](src/EspMain.cpp:194)): `x509` — локальная
переменная, а `setClientRSACert` сохраняет указатель на неё; после выхода из
функции указатель висячий (privKey к тому же утекает). Пока IoT отключён
(`if (true) return;`), не стреляет, но при реанимации Яндекс-интеграции TLS
начнёт падать «загадочно». Оба объекта должны быть статическими/глобальными.

---

## 4. Прочее
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

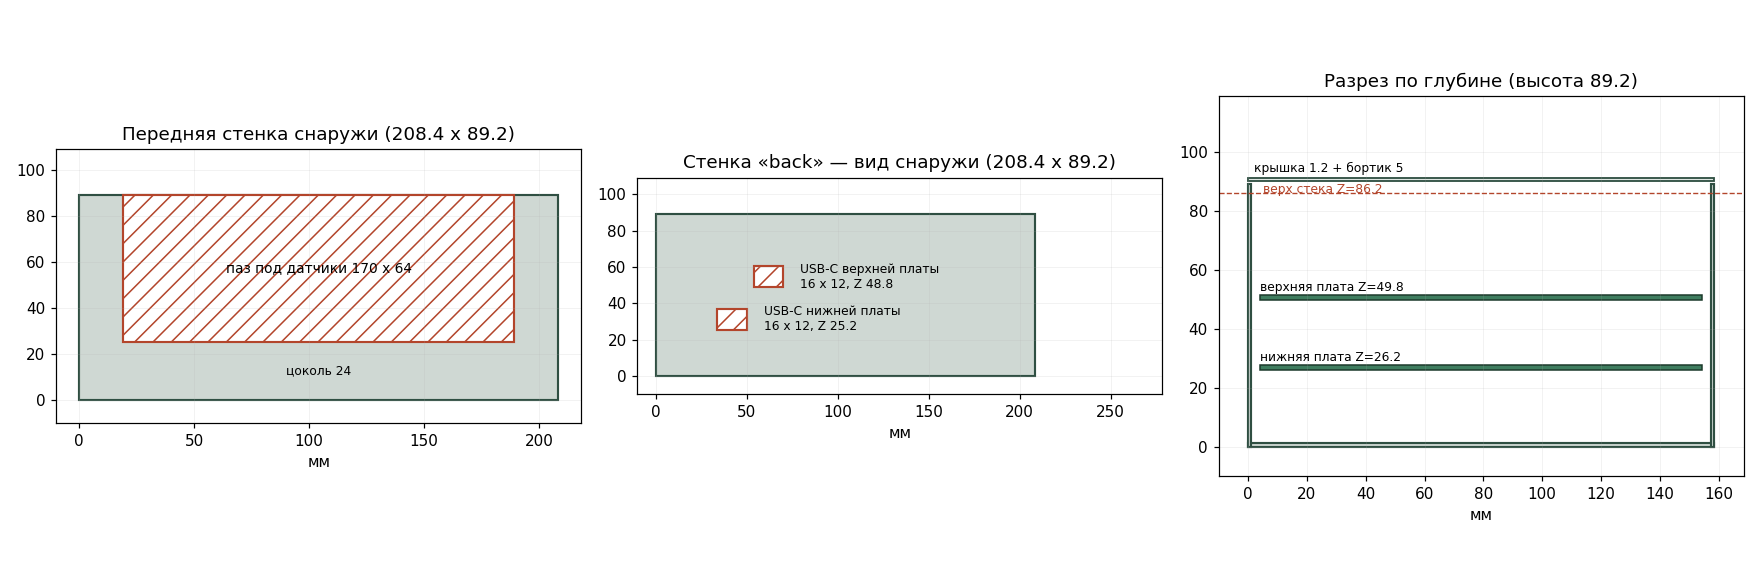
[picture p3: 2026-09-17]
case/aw_case_drawing.png

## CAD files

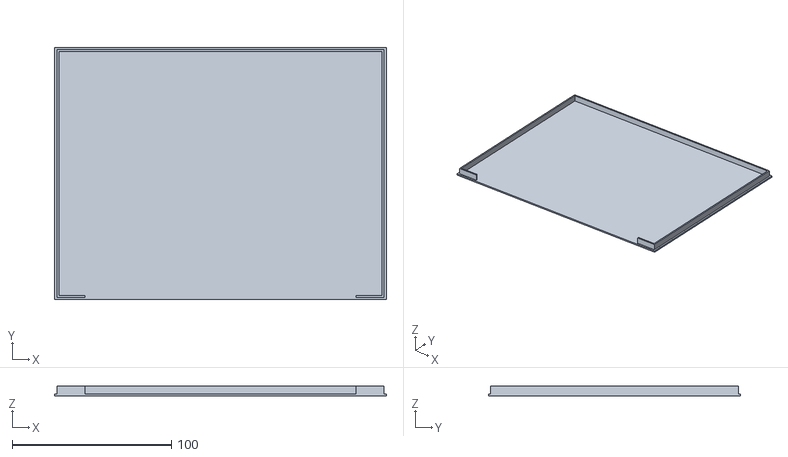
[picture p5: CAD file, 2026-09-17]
case/aw_case_lid.stl
208.4 x 158.4 x 6.20

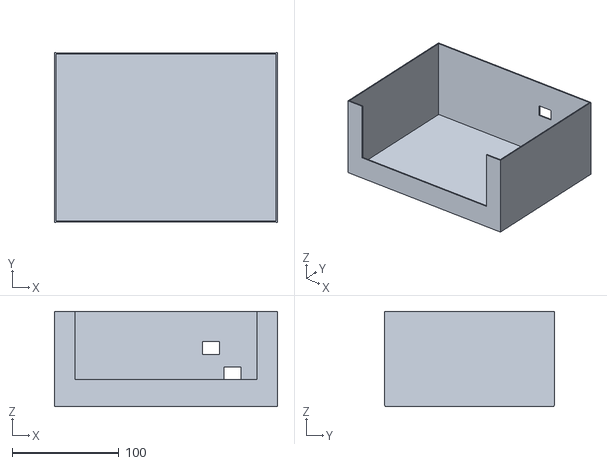
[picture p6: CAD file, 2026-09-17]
case/aw_case_body.stl
208.4 x 158.4 x 89.2

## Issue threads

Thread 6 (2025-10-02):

Срочный запуск в боевую эксплуатацию

m9ist, 2025-10-02:
- [x] время в логирование
- [x] логирование на сд карту, запускаться без нее
- [x] нарисовать простенький экранчик для индикации работы
- [ ] полить растение и собрать баунды за сутки, 2, 3, 4
- [x] отладить время > нужного, поэтому запусти задание
- [ ] сохранение времени задания при перезагрузке
- [x] собрать схему с клапанами и мотором
- [x] отладить функцию поливки растения (по кнопке)
- [x] посчитать скорость поливки в секундах
- [ ] написать финальный алгоритм поливки через баунды, нарисовать стейт
- [ ] найти блок питания и запустить в бою схему

Со звездочкой
- [ ] нарисовать на экране стейты за последние 4 дня для включенных растений
- [x] разобраться с SD картой
- [ ] перезапуск в бою SD карты?

Closed 2025-10-05.

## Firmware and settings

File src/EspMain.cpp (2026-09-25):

// #define WITHOUT_ARDUINO

#include <ArduinoJson.h>
#include <ArduinoOTA.h>
#include <CmdHandler.h>
#include <CommandParser.h>
#include <Communication.h>
#include <ESP8266WiFi.h>
#include <EspLogger.h>
#include <PubSubClient.h>
#include <State.h>
#include <Timer.h>
#include <time.h>

// Блок из SecretHolder, чтобы не заводить лишний .h файл, нужно там реализовать
// эти методы
String ssid();
String wifiPasswork();
String mqttUser();
String mqttPassword();

// Брокер (homelab/stacks/mqtt, ADR-0001) — единственная точка подключения
// ESP наружу. Хост/порт не секрет (LAN-адрес, как и upload_port в
// platformio.ini), учётка esp — в SecretHolder.
const char* const MQTT_HOST = "192.168.1.146";
const uint16_t MQTT_PORT = 1883;
const char* const MQTT_TOPIC_ONLINE = "aw/online";
const char* const MQTT_TOPIC_LOG = "aw/log/esp";
// Команда от aw-server (issue #17), passthrough в UART после валидации границ
const char* const MQTT_TOPIC_CMD = "aw/cmd";
// Событие для человека (aw-server пересылает в Telegram) — отказы Команд,
// графики, сообщения от Mega (бывший logTelegram/arduino_tg)
const char* const MQTT_TOPIC_EVENT = "aw/event";
// последний Стейт от Mega, retained — aw-server отвечает /state и шлёт часовую
// сводку из него без похода на ESP
const char* const MQTT_TOPIC_STATE = "aw/state";
// сколько строк из RAM-кольца лога досылаем за один тик loop() — чтобы не
// блокировать UART-обмен с Mega при большой досылке после реконнекта
const uint8_t MQTT_FLUSH_LINES_PER_TICK = 3;

EspLogger logger;

// Обёртка PubSubClient под интерфейс ILogSink (см. EspLogger.h) — держит
// MQTT-специфику вне EspLogger.h.
class MqttLogSink : public ILogSink {
 public:
  MqttLogSink(PubSubClient& client, const char* topic)
      : client_(client), topic_(topic) {}
  bool connected() override { return client_.connected(); }
  bool publish(const char* json) override {
    return client_.publish(topic_, json);
  }

 private:
  PubSubClient& client_;
  const char* topic_;
};

WiFiClient mqttNetClient;
PubSubClient mqttClient(mqttNetClient);
MqttLogSink mqttLogSink(mqttClient, MQTT_TOPIC_LOG);

// реконнект по таймеру: одна попытка раз в интервал. Сам connect()
// синхронный — при молчащем хосте блокирует loop() на таймаут TCP
// (ограничен setTimeout в setup, ~2с) — честная цена PubSubClient,
// «неблокирующим» это не назвать, но пауза ограничена и редка (раз в 5с
// только пока брокер лежит).
Timer timerMqttReconnect;
const Duration intervalMqttReconnect = Timer::Seconds(5);

Communication comm = Communication(Serial, logger, true);

String getTimestamp() {
  time_t now = time(nullptr);
  struct tm timeinfo;
  localtime_r(&now, &timeinfo);

  char buffer[20];
  strftime(buffer, sizeof(buffer), "%Y-%m-%d %H:%M:%S", &timeinfo);
  return String(buffer);
}

void serialLog(const String& command, const String& s) {
#ifdef DEBUG_LOG
  JsonDocument json;
  json[COMMAND_KEY] = command;
  json[F("timestamp")] = getTimestamp();
  json[F("log")] = s;

  String sendJson;
  serializeJson(json, sendJson);
#ifdef WITHOUT_ARDUINO
  Serial.println(sendJson);
#else
  logger.println(sendJson);
  // Логи ESP уходят только в MQTT: Mega их всё равно игнорирует, а лишняя
  // отправка в UART, пока Mega минутами занята поливом, рвала связь (дневной
  // полив 25.09). В UART — только команды.
  if (command != String(ESP_COMMAND_LOG)) {
    comm.communicationSendMessage(sendJson);
  }
#endif
#endif
}

void serialLog(const String& s) { serialLog(ESP_COMMAND_LOG, s); }

// Отправка в ардуино команды с растением и объёмом (esp_water / esp_plant_conf)
void serialPlantCommand(const String& command, int id, int amount) {
  JsonDocument json;
  json[COMMAND_KEY] = command;
  json[F("timestamp")] = getTimestamp();
  json[F("plantId")] = id;
  json[F("amountMl")] = amount;

  String sendJson;
  serializeJson(json, sendJson);
  logger.println(sendJson);
  comm.communicationSendMessage(sendJson);
}

// Отправка в ардуино команды оживления клапана (esp_wakeup): id плюс формула
// прогона. Дефолты формулы подставляет aw-server — сюда всегда приезжают все
// четыре числа.
void serialWakeupCommand(int id, int longCycles, int longOnMs, int shortCycles,
                         int shortOnMs) {
  JsonDocument json;
  json[COMMAND_KEY] = ESP_COMMAND_WAKEUP;
  json[F("timestamp")] = getTimestamp();
  json[F("plantId")] = id;
  json[F("longCycles")] = longCycles;
  json[F("longOnMs")] = longOnMs;
  json[F("shortCycles")] = shortCycles;
  json[F("shortOnMs")] = shortOnMs;

  String sendJson;
  serializeJson(json, sendJson);
  logger.println(sendJson);
  comm.communicationSendMessage(sendJson);
}

void serialTimeSynced() {
  JsonDocument json;
  json[COMMAND_KEY] = ESP_COMMAND_TIME_SYNCED;
  json[F("timestamp")] = getTimestamp();
  time_t now = time(nullptr);
  struct tm timeinfo;
  // localtime, а не gmtime: в RTC ардуины и на экран должно уехать местное
  localtime_r(&now, &timeinfo);
  serializeTimeInfo(timeinfo, json);
  String sendJson;
  serializeJson(json, sendJson);
  logger.println(sendJson);
  comm.communicationSendMessage(sendJson);
}

void serialError(const String& s) { serialLog(ESP_COMMAND_LOG, s); }

String plantCommandRejectReason() {
  return (String)F("Rejected: plant id must be 0..") + (PLANTS_AMOUNT - 1) +
         F(", amount 0..") + MAX_WATER_AMOUNT_ML + F("ml");
}

// Границы значений проверяем ещё на ESP: на Mega int 16-битный, без этой
// проверки plant65536 усекался бы до валидного id. Mega проверяет тоже
// (защита своего протокола), но с менее внятным сообщением пользователю.
// Арифметика границ — в CmdHandler.h::isPlantCommandInBounds (тестируется
// native); эта функция остаётся Arduino-обёрткой с прежним сайд-эффектом
// (лог отказа) — вызывается из handleCmdMessage при разборе aw/cmd (issue #17).
bool checkPlantCommandBounds(int id, int amount) {
  if (cmdhandler::isPlantCommandInBounds(id, amount, PLANTS_AMOUNT,
                                         MAX_WATER_AMOUNT_ML)) {
    return true;
  }
  serialLog(plantCommandRejectReason());
  return false;
}

String wakeupCommandRejectReason() {
  return (String)F("Rejected: plant id must be 0..") + (PLANTS_AMOUNT - 1) +
         F(", cycles 0..") + MAX_WAKEUP_CYCLES + F(", on 0..") +
         MAX_WAKEUP_ON_MS + F("ms");
}

// Границы параметров оживления — та же схема, что у checkPlantCommandBounds:
// арифметика в CmdHandler.h (тестируется native), здесь Arduino-обёртка с
// логом отказа.
bool checkWakeupCommandBounds(int id, int longCycles, int longOnMs,
                              int shortCycles, int shortOnMs) {
  if (cmdhandler::isWakeupCommandInBounds(id, longCycles, longOnMs, shortCycles,
                                          shortOnMs, PLANTS_AMOUNT,
                                          MAX_WAKEUP_CYCLES,
                                          MAX_WAKEUP_ON_MS)) {
    return true;
  }
  serialLog(wakeupCommandRejectReason());
  return false;
}

bool isTimeInited() { return time(nullptr) > 1000000000; }

void checkWifi() {
  if (WiFi.status() == WL_CONNECTED) {
    return;
  }

  int i = 0;
  while (WiFi.status() != WL_CONNECTED) {  // Ожидаем подключения к Wi-Fi
    serialLog(F("Waiting wi-fi"));
    delay(1000);
    i++;
    if (i > 15) {
      serialLog(F("Unable to connect wifi, restart."));
      ESP.restart();
    }
  }

  // Выводим информацию о подключении
  serialLog(F("Connected to ") + ssid());
  serialLog(WiFi.localIP().toString());
}

// Одна попытка подключения к брокеру (без ожидания результата циклом —
// вызывается из mqttLoop() не чаще, чем раз в intervalMqttReconnect).
// LWT: aw/online=0 retained, qos1 — если ESP пропадёт без явного
// отключения, брокер сам выставит offline. После успешного коннекта явно
// публикуем aw/online=1 retained.
void mqttConnect() {
  bool ok =
      mqttClient.connect("esp-autowatering", mqttUser().c_str(),
                          mqttPassword().c_str(), MQTT_TOPIC_ONLINE,
                          /*willQos=*/1, /*willRetain=*/true, "0");
  if (ok) {
    mqttClient.publish(MQTT_TOPIC_ONLINE, "1", true);
    // Команда из aw/cmd, QoS1 (issue #17) — публикует aw-server только с
    // QoS0 (PubSubClient publish тоже без выбора QoS), но подписка на QoS1
    // задаёт верхнюю границу, если это изменится на стороне aw-server
    mqttClient.subscribe(MQTT_TOPIC_CMD, 1);
    serialLog(F("MQTT connected"));
  } else {
    serialLog((String)F("MQTT connect failed, rc=") + mqttClient.state());
  }
}

// aw/event — Событие для человека (доставляет aw-server в Telegram): отказы
// Команд, ASCII-графики, сообщения от Mega (бывший logTelegram/arduino_tg).
// При офлайне брокера публикация просто теряется (осознанно — в RAM-кольцо
// уходят только логи, см. EspLogger.h) — неудачу логируем через логгер.
void publishEvent(const char* type, const String& text) {
  JsonDocument json;
  json[F("type")] = type;
  json[F("text")] = text;
  String out;
  serializeJson(json, out);
  if (!mqttClient.publish(MQTT_TOPIC_EVENT, out.c_str())) {
    serialLog((String)F("Failed to publish aw/event: ") + out);
  }
}

// Обработка aw/cmd (issue #17): разбор и распознавание команды — в
// CmdHandler.h (тестируется native), границы id/объёма — через сохранённую
// checkPlantCommandBounds; форвард в UART — как раньше (serialPlantCommand /
// serialLog(ESP_COMMAND_*), сохранено с #13). Невалидная Команда — Событие-
// отказ в aw/event и лог.
void handleCmdMessage(const uint8_t* payload, unsigned int length) {
  cmdhandler::Decision d =
      cmdhandler::decideCmd((const char*)payload, length);
  switch (d.action) {
    case cmdhandler::Action::kWater:
    case cmdhandler::Action::kConfig:
      if (!checkPlantCommandBounds(d.plantId, d.amountMl)) {
        publishEvent("reject", plantCommandRejectReason());
        return;
      }
      serialPlantCommand(d.action == cmdhandler::Action::kWater
                             ? ESP_COMMAND_WATER_PLANT
                             : ESP_COMMAND_CONFIG_PLANT,
                         d.plantId, d.amountMl);
      return;
    case cmdhandler::Action::kDaily:
      serialLog(ESP_COMMAND_DAILY_TASK, F("From aw/cmd"));
      return;
    case cmdhandler::Action::kCheckValves:
      serialLog(ESP_COMMAND_CHECK_VALVES, F("From aw/cmd"));
      return;
    case cmdhandler::Action::kSwitchPump:
      serialLog(ESP_COMMAND_SWITCH_PUMP, F("From aw/cmd"));
      return;
    case cmdhandler::Action::kWakeup:
      if (!checkWakeupCommandBounds(d.plantId, d.longCycles, d.longOnMs,
                                    d.shortCycles, d.shortOnMs)) {
        publishEvent("reject", wakeupCommandRejectReason());
        return;
      }
      serialWakeupCommand(d.plantId, d.longCycles, d.longOnMs, d.shortCycles,
                          d.shortOnMs);
      return;
    case cmdhandler::Action::kReject:
    default:
      serialLog(d.reason);
      publishEvent("reject", d.reason);
      return;
  }
}

void onMqttMessage(char* topic, uint8_t* payload, unsigned int length) {
  if (strcmp(topic, MQTT_TOPIC_CMD) == 0) {
    handleCmdMessage(payload, length);
  }
}

// Первая строка loop(): неблокирующий реконнект по таймеру (без
// delay-циклов — при недоступном брокере UART-обмен с Mega не деградирует)
// и порционная досылка RAM-кольца лога после реконнекта.
void mqttLoop() {
  mqttClient.loop();
  if (!mqttClient.connected()) {
    if (timerMqttReconnect.expired()) {
      timerMqttReconnect.setDuration(intervalMqttReconnect);
      mqttConnect();
    }
    return;
  }

  // маркер потерь и досылка кольца — внутри flushPending (см. EspLogger.h)
  logger.flushPending(MQTT_FLUSH_LINES_PER_TICK);
}

void setupOTA() {
  ArduinoOTA.onStart([]() {
    String type;
    if (ArduinoOTA.getCommand() == U_FLASH) {
      type = F("sketch");
    } else {  // U_FS
      type = F("filesystem");
    }

    // NOTE: if updating FS this would be the place to unmount FS using FS.end()
    serialLog(F("Start updating ") + type);
  });
  ArduinoOTA.onEnd([]() { serialLog(F("End")); });
  ArduinoOTA.onProgress([](unsigned int progress, unsigned int total) {
    Serial.printf("Progress: %u%%\r", (progress / (total / 100)));
  });
  ArduinoOTA.onError([](ota_error_t error) {
    Serial.printf("Error[%u]: ", error);
    if (error == OTA_AUTH_ERROR) {
      Serial.println(F("Auth Failed"));
    } else if (error == OTA_BEGIN_ERROR) {
      Serial.println(F("Begin Failed"));
    } else if (error == OTA_CONNECT_ERROR) {
      Serial.println(F("Connect Failed"));
    } else if (error == OTA_RECEIVE_ERROR) {
      Serial.println(F("Receive Failed"));
    } else if (error == OTA_END_ERROR) {
      Serial.println(F("End Failed"));
    }
  });
  ArduinoOTA.begin();
}

void setup() {
#ifdef WITHOUT_ARDUINO
  Serial.begin(9600);  // для отладки
  delay(3000);
#else
  Serial.begin(115200);  // для общения с ардуино
#endif
  while (!Serial) {
  }

  // сток лога на MQTT подключаем сразу — до готовности WiFi/брокера строки
  // просто копятся в RAM-кольце EspLogger и досылаются после первого коннекта
  logger.setTimestampProvider(getTimestamp);
  logger.setSink(&mqttLogSink);

  serialLog("Start working");

  // Устанавливаем Wi-Fi модуль в режим клиента (STA)
  WiFi.mode(WIFI_STA);
  // Устанавливаем ssid и пароль от сети, подключаемся
  WiFi.begin(ssid(), wifiPasswork());
  checkWifi();
  setupOTA();

  // таймаут TCP-connect/read: PubSubClient::connect синхронный, без этого
  // молчащий хост держал бы loop() ~5с на каждой попытке реконнекта
  mqttNetClient.setTimeout(2000);
  mqttClient.setServer(MQTT_HOST, MQTT_PORT);
  mqttClient.setBufferSize(1024);  // state-JSON больше дефолтных 256Б (#17)
  mqttClient.setKeepAlive(30);
  mqttClient.setCallback(onMqttMessage);  // разбор входящих aw/cmd (#17)
  timerMqttReconnect.setDuration(intervalMqttReconnect);
  mqttConnect();

  serialLog(F("Start sync time"));
  // POSIX TZ: знак инвертирован, московское UTC+3 записывается как MSK-3
  configTime("MSK-3", F("ntp6.ntp-servers.net"), F("1.ru.pool.ntp.org"),
             F("ntp.ix.ru"));
  while (!isTimeInited()) {
    serialLog(F("Waiting for time sync..."));
    delay(1000);
  }
  serialTimeSynced();

  serialLog(F("Esp started successfully."));
}

void processMessageArduino(String message) {
  logger.println(getTimestamp());
  logger.println(message);
  JsonDocument doc;
  DeserializationError error = deserializeJson(doc, message);
  if (error != DeserializationError::Ok) {
    serialError((String)F("Can't deserialize ") + error.c_str());
    serialLog(message);
  } else {
    const char* command = doc[COMMAND_KEY];
    if ((String)ARDUINO_COMMAND_STATE == command) {
      // retained aw/state (issue #17): aw-server отвечает /state, шлёт
      // часовую сводку и пушит метрики в Loki (issue #20). Кадр Mega уходит
      // как есть — без deserializeState/serializeState туда-обратно: aw-server
      // читает ключи через .get(), лишние поля ("c","timestamp") не мешают
      if (!mqttClient.publish(MQTT_TOPIC_STATE, message.c_str(), true)) {
        serialLog((String)F("Failed to publish aw/state: ") + message);
      }
    } else if ((String)ARDUINO_SEND_TELEGRAM == command) {
      // раньше пересылалось в телеграм (logTelegram) — теперь Событие в
      // aw/event, доставляет aw-server (issue #17)
      const char* tgMessage = doc[F("message")];
      if (tgMessage == nullptr || tgMessage[0] == '\0') {
        // arduino_tg без message: aw-server молча дропает пустой text —
        // след должен остаться хотя бы в логах (ревью: «уведомление
        // исчезает без следа»)
        serialError(F("arduino_tg without message field"));
      } else {
        publishEvent("event", tgMessage);
      }
    } else {
      serialError((String)F("Unknown command ") + command);
      serialLog(message);
    }
  }
}

void loop() {
  mqttLoop();
  ArduinoOTA.handle();
  // todo вынести в другой поток? <<<<<<<<<<<<<<<<<<<<<<
  comm.communicationTick();
  if (comm.communicationHasMessage()) {
    processMessageArduino(comm.communicationGetMessage());
    return;
  }
}

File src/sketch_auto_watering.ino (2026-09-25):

#include <ArduinoJson.h>
#include <AwClock.h>
#include <AwLogging.h>
#include <Communication.h>
#include <Ds1302.h>
#include <EEPROM.h>
#include <Pomp.h>
#include <Screen.h>
#include <Sensors.h>
#include <State.h>
#include <Time.h>
#include <Timer.h>
#include <avr/wdt.h>

#define IS_DEBUG true

// Alt + Shift + F - автоформатирование кода
// Ctrl + Alt + B - компиляция
// Ctrl + Alt + U - загрузка прошивки

State global_state;
AwLogging logger;
Sensors sensors;
AwClock awClock;
Pomp pomp;

void stateUpdated() {
  // todo подумать о том, чтобы сохранять источник, время, "широту обновления"
  global_state.updated = true;
}

Timer timerSensorsCheck;
const Duration repeatIntervalSensorsCheck = Timer::Minutes(1);
Communication comm = Communication(Serial3, Serial, false);

void loadStateEEPROM() {
  int address = 0;
  int version;
  EEPROM.get(address, version);
  address += sizeof(int);
  int storedSize;
  EEPROM.get(address, storedSize);
  address += sizeof(int);
  // размер State проверяем вместе с версией: страховка от забытого
  // bump'а EEPROM_VERSION при изменении структуры
  if (version != EEPROM_VERSION || storedSize != (int)sizeof(State)) {
    Serial.println("Bad version of EEPROM in memory");
  } else {
    EEPROM.get(address, global_state);
    // activePump идёт индексом в lastPumpMl/lastPumpRunAt: перевёрнутый бит в
    // этом байте (версия и размер при этом целы) дал бы запись мимо массива,
    // в соседние поля State, и она осталась бы в EEPROM (ревью GLM)
    if (global_state.activePump > PUMP_2) global_state.activePump = PUMP_2;
    Serial.println("Loaded state from eeprom");
  }
}

void saveStateEEPROM() {
  int address = 0;
  int version = EEPROM_VERSION;
  EEPROM.put(address, version);
  address += sizeof(int);
  EEPROM.put(address, (int)sizeof(State));
  address += sizeof(int);
  EEPROM.put(address, global_state);
#ifdef DEBUG_LOG
  logger.writeln(F("Saved state to eeprom"));
#endif
}

int freeRam() {
  extern int __heap_start, *__brkval;
  int v;
  return (int)&v - (__brkval == 0 ? (int)&__heap_start : (int)__brkval);
}

void logFreeRam() {
  global_state.freeMemorySize = freeRam();
  logger.logFreeRam(global_state.freeMemorySize);
}

// Долгий delay с периодическими wdt_reset. WDT настроен на 8 секунд
// (см. setup), поэтому простой delay(N) при N >= 8000 кикает плату.
// Шаг 1с — есть запас, и резет идёт перед сном, между кусками и в конце.
void sleepWithWdt(unsigned long ms) {
  const unsigned long CHUNK_MS = 1000;
  wdt_reset();
  unsigned long elapsed = 0;
  while (elapsed < ms) {
    unsigned long step = (ms - elapsed) < CHUNK_MS ? (ms - elapsed) : CHUNK_MS;
    delay(step);
    wdt_reset();
    elapsed += step;
  }
}

void setup() {
  Serial.begin(9600);
  Serial3.begin(115200);
  while (!Serial || !Serial3) {
  }

  Serial.println(F("Start working"));
  wdt_enable(WDTO_8S);
  logFreeRam();
  loadStateEEPROM();
  global_state.sdInited = false;
  global_state.espConnectedAndTimeSynced = false;
  logger.init(global_state);
  awClock.initClock(global_state, logger);
  initScreen(logger);

  sensors.init(logger, global_state);
  pomp.initPomp(logger);
  pomp.updatePlantsState(global_state);

  timerSensorsCheck.setDuration(Timer::Seconds(5));
  logger.writeln(F("End init arduino"));
}

uint32_t test_time = 0;

// Писатель для serializeJson, дописывающий в String без перевыделений: в
// заранее выделенном буфере concat места хватает всегда. Сериализовать прямо
// в String нельзя — ArduinoJson сначала обнуляет её через
// str = (const char*)0, а на AVR это free() буфера, и reserve пропадал.
struct ReservedStringWriter {
  String& out;
  size_t write(uint8_t c) { return out.concat((char)c) ? 1 : 0; }
  size_t write(const uint8_t* s, size_t n) {
    for (size_t i = 0; i < n; i++) {
      if (!write(s[i])) return i;
    }
    return n;
  }
};

// Сериализует doc в out одним выделением памяти. false — памяти не хватило,
// out пустая: такое сообщение не шлём, пустая строка ломала ESP.
bool serializeJsonOnce(const JsonDocument& doc, String& out) {
  if (!out.reserve(measureJson(doc))) return false;
  ReservedStringWriter writer{out};
  serializeJson(doc, writer);
  return true;
}

void sendTelegram(String message) {
  JsonDocument toSend;
  toSend[COMMAND_KEY] = ARDUINO_SEND_TELEGRAM;
  toSend[F("message")] = (String)F("Arduino: ") + message;
  String out;
  if (!serializeJsonOnce(toSend, out)) {
    logger.writeln(F("No memory for telegram message"));
    return;
  }
#ifdef DEBUG_LOG
  logger.writeln(out);
#endif
  comm.communicationSendMessage(static_cast<String&&>(out));
  logFreeRam();
}

void waterPlant(int id, int amount) {
  String info =
      pomp.waterPlant(id, amount, global_state, dateToEpoch(awClock.getNow()),
                      logger);
  // результат пуска помпы лёг в стейт (issue #22) — сохраняем и отдаём наверх
  saveStateEEPROM();
  stateUpdated();
  logFreeRam();
  sendTelegram(info);
  delay(10);
}

// Дневной полив держит loop() минутами, и без этого отчёты копились в очереди
// и уходили в ESP пачкой в конце — на такой пачке связь срывалась и отчёты
// терялись. Один тик отправляет не больше одного сообщения, а может уйти на
// чтение входящего или на восстановление связи, поэтому тиков несколько.
void flushCommunication() {
  for (int i = 0; i < 3; i++) {
    comm.communicationTick();
    wdt_reset();
  }
}

void runDailyCommand() {
  logger.buzzerCommand();
  sendTelegram(F("Start daily task."));
  flushCommunication();
  for (int i = 0; i < PLANTS_AMOUNT; i++) {
    logFreeRam();
    const Plant& plant = global_state.plants[i];
    if (plant.isOn != PLANT_IS_ON || plant.dailyAmountMl <= 0) {
      continue;
    }
    waterPlant(i, plant.dailyAmountMl);
    flushCommunication();
  }
  sendTelegram((String)F("Daily task is completed. Free mem = ") + freeRam());
}

// Валидация команд с plantId/amountMl: id за пределами массива plants — это
// запись в чужую память и bitWrite с UB (мог открыться случайный клапан),
// amount без лимита — потоп от опечатки в Telegram.
// long, а не int: на AVR int 16-битный, plant65536 усёкся бы до валидного
// id=0 ещё до проверки.
bool isValidPlantCommand(long id, long amount) {
  if (id < 0 || id >= PLANTS_AMOUNT) {
    sendTelegram((String)F("Rejected: bad plant id ") + id);
    return false;
  }
  if (amount < 0 || amount > MAX_WATER_AMOUNT_ML) {
    sendTelegram((String)F("Rejected: bad amount ") + amount + F("ml, max ") +
                 MAX_WATER_AMOUNT_ML + F("ml"));
    return false;
  }
  return true;
}
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

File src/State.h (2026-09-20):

#ifndef STATE_H
#define STATE_H
#include <ArduinoJson.h>
#include <Ds1302.h>
#include <Time.h>

#define PLANT_IS_ON 10
#define PLANT_IS_OFF_USER 1
#define PLANT_IS_OFF_EXCEPTION 2
#define PLANT_IS_UNDEFINED -1
#define PLANTS_AMOUNT 16
// Помпы: позиционные номера, наружу (Telegram, aw/state) — pump1/pump2.
// Индекс в массивах стейта, не пин: пины живут в Pomp.h.
#define PUMPS_AMOUNT 2
#define PUMP_1 0
#define PUMP_2 1
// todo удалить: не используется, дубль COMMUNICATION_DATA_CHUNK_SIZE
#define DATA_CHUNK_SIZE 62  // SERIAL_TX_BUFFER_SIZE
#define UNDEFINED_PLANT_VALUE 1022
// максимальный объём одной команды полива (и дневной нормы), защита от опечаток
#define MAX_WATER_AMOUNT_ML 200

// Оживление клапана (wakeup): формула прогона — сначала длинные «дожимы»
// (клапан после простоя не открывается, но открывается, если подержать
// напряжение), потом короткие щелчки, расхаживающие ход.
#define WAKEUP_LONG_CYCLES 3
#define WAKEUP_LONG_ON_MS 2000
#define WAKEUP_SHORT_CYCLES 7
#define WAKEUP_SHORT_ON_MS 300
// Пауза между циклами одна на обе фазы, в параметры команды не выносится.
#define WAKEUP_OFF_MS 300
// Границы параметров команды — отсев опечаток, как MAX_WATER_AMOUNT_ML.
// Это не предел длительности прогона: кнопка крутит формулу, пока её держат.
#define MAX_WAKEUP_CYCLES 30
#define MAX_WAKEUP_ON_MS 5000

#define COMMAND_KEY F("c")
#define ESP_COMMAND_LOG F("esp_log")
#define ESP_COMMAND_TIME_SYNCED F("esp_ntp")
#define ESP_COMMAND_WATER_PLANT F("esp_water")
#define ESP_COMMAND_CONFIG_PLANT F("esp_plant_conf")
#define ESP_COMMAND_DAILY_TASK F("esp_daily")
#define ESP_COMMAND_CHECK_VALVES F("esp_check_valves")
#define ESP_COMMAND_SWITCH_PUMP F("esp_pump")
#define ESP_COMMAND_WAKEUP F("esp_wakeup")

#define ARDUINO_COMMAND_STATE F("state")
#define ARDUINO_SEND_TELEGRAM F("arduino_tg")

#define EEPROM_VERSION 7

// Изменил, обнови EEPROM_VERSION
struct Plant {
  // включено ли растение PLANT_IS_OFF_USER - выключен тумблер ??? - отключение
  // по ошибке PLANT_IS_ON - включено
  uint8_t isOn = PLANT_IS_UNDEFINED;
  // краткое описание растения (горшок, название и тд)
  char plantName[10] = "";
  // оригинальная влажность от датчика влажности
  uint16_t originalValue = UNDEFINED_PLANT_VALUE;

  uint16_t dailyAmountMl = 0;
};

// Изменил, обнови EEPROM_VERSION
struct State {
  // если что-то где-то обновилось и можно отослать стейт в esp и лог
  bool updated = false;

  bool sdInited = false;
  bool pompIsOn = false;

  // Активная помпа: PUMP_1 (D6) или PUMP_2 (D5). Переживает ребут, иначе
  // после каждого ресета система возвращалась бы на помпу, которую только
  // что признали дохлой. Дефолт PUMP_2 — поведение прошивки до issue #22.
  uint8_t activePump = PUMP_2;
  // Результат последнего пуска каждой помпы: сколько мл намерил расходомер
  // и когда это было (dateToEpoch, 0 — ни разу не запускалась). Вердикт
  // «резервная жива» ручной, по этим двум числам в /state (issue #22).
  uint16_t lastPumpMl[PUMPS_AMOUNT] = {0, 0};
  uint32_t lastPumpRunAt[PUMPS_AMOUNT] = {0, 0};
  // Снимок часов Mega на момент сборки Стейта: по нему aw-server считает
  // возраст пусков помп, не пытаясь свести свои часы с RTC ардуины.
  uint32_t nowEpoch = 0;
  bool espConnectedAndTimeSynced = false;
  bool temperatureSensorInited = false;
  // bool hasWaterLevel = false;

  int freeMemorySize = 0;

  Plant plants[PLANTS_AMOUNT];

  // следующая глобальная проливка растений
  // todo не используется: планировщик не реализован (см. AwClock::runNextDayTask)
  Ds1302::DateTime nextTaskRuning;
  // загрузка приложения
  Ds1302::DateTime startUpDate;

  Ds1302::DateTime lastSensorCheck;

  float temperature;
  float humidity;

  // последняя проверка датчиков влажности
  // time_t lastCheck;
  // частота проверки датчиков влажности в минутах
  // int checkFrequencyInMinutes = 30;
  // int checkFrequencyInMinutes = 30;
  // частота отправки данных в яндекс
  // todo удалить: не используется, на ESP свой таймер
  int sendIotFrequencyInMinutes = 60;
  // Время последней синхронизации часов
  // Список критических ошибок
};

// функции в хедере, включаемом из нескольких мест — обязаны быть inline (ODR)
inline String dateToString(Ds1302::DateTime now) {
  String out;

  out += "20";
  out += now.year;  // 00-99
  out += "-";
  if (now.month < 10) out += '0';
  out += now.month;  // 01-12
  out += '-';
  if (now.day < 10) out += '0';
  out += now.day;
  out += ' ';
  if (now.hour < 10) out += '0';
  out += now.hour;  // 00-23
  out += ':';
  if (now.minute < 10) out += '0';
  out += now.minute;  // 00-59
  out += ':';
  if (now.second < 10) out += '0';
  out += now.second;  // 00-59
  return out;
}

// Время RTC в линейные секунды (эпоха avr-libc — с 2000-01-01) для
// арифметики возраста: сравнивать Ds1302::DateTime поэлементно ради
// «сколько минут назад» неудобно. 0 считаем за «события не было» —
// коллизия только с полуночью 2000-01-01, то есть с неинициализированным
// RTC, где значение и так бессмысленно.
// Считаем сами, а не через libc: mk_gmtime есть только в avr-libc (ESP не
// собирается), а mktime/timegm на ESP отсчитывают от 1970 против 2000 у
// AVR — один и тот же кадр получал бы разные числа на разных прошивках.
inline uint32_t dateToEpoch(Ds1302::DateTime dt) {
  // дней с начала года до начала месяца, невисокосный год
  static const uint16_t daysBeforeMonth[12] = {0,   31,  59,  90,  120, 151,
                                               181, 212, 243, 273, 304, 334};
  if (dt.month < 1 || dt.month > 12) return 0;
  uint16_t year = dt.year;  // 00-99 от 2000
  // 2000 — високосный, и в диапазоне 2000-2099 правило «каждые 4 года»
  // работает без исключений (2100 уже вне разрядности Ds1302)
  uint32_t days = (uint32_t)year * 365 + (year + 3) / 4;
  days += daysBeforeMonth[dt.month - 1];
  if (dt.month > 2 && (year % 4) == 0) days++;
  days += dt.day - 1;
  return days * 86400UL + (uint32_t)dt.hour * 3600UL +
         (uint32_t)dt.minute * 60UL + dt.second;
}

inline bool isDefined(const Plant& plant) {
  // todo <<<<<< когда будут ошибки учесть их
  return plant.isOn == PLANT_IS_ON;
  //|| plant.originalValue < UNDEFINED_PLANT_VALUE || plant.plantName != "";
}
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

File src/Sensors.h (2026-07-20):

#ifndef SENSORS_H
#define SENSORS_H
#include <SHT31_SWW.h>

#include "AwLogging.h"
#include "State.h"

#define PIN_SERNSOR_S0 26
#define PIN_SERNSOR_S1 28
#define PIN_SERNSOR_S2 30
#define PIN_SERNSOR_S3 32

#define PIN_INPUT_SENSOR 0

#define PIN_TEMP_SDA 19
#define PIN_TEMP_SCL 21

#define PIN_WATER_LEVEL A1

class Sensors {
 protected:
  SoftwareWire wireTempSensor = SoftwareWire(PIN_TEMP_SDA, PIN_TEMP_SCL);
  SHT31_SWW sht31 = SHT31_SWW(0x44, &wireTempSensor);

  void loopSoilMoistureSensors(State& state) {
    for (int i = 0; i < PLANTS_AMOUNT; i++) {
      digitalWrite(PIN_SERNSOR_S0, bitRead(i, 0));
      digitalWrite(PIN_SERNSOR_S1, bitRead(i, 1));
      digitalWrite(PIN_SERNSOR_S2, bitRead(i, 2));
      digitalWrite(PIN_SERNSOR_S3, bitRead(i, 3));
      // Первый замер после переключения канала выбрасываем: вход АЦП ещё
      // держит заряд предыдущего датчика (мультиплексер + высокоомный
      // источник), первый analogRead частично показывает соседний канал.
      analogRead(PIN_INPUT_SENSOR);
      int read = analogRead(PIN_INPUT_SENSOR);
      state.plants[i].originalValue = read;
    }
  }

 public:
  void init(AwLogging& logger, State& state) {
    logger.writeln(F("Start init sensors"));

    // работа с датчиком влажности и температуры
    wireTempSensor.begin();
    bool b = sht31.begin();
    logger.writeln((String)F("SHT31 connection: ") + b);
    state.temperatureSensorInited = b;

    // схема с мультиплексором для датчиков влажности почвы
    pinMode(PIN_SERNSOR_S0, OUTPUT);  // s0
    pinMode(PIN_SERNSOR_S1, OUTPUT);  // s1
    pinMode(PIN_SERNSOR_S2, OUTPUT);
    pinMode(PIN_SERNSOR_S3, OUTPUT);

    pinMode(PIN_WATER_LEVEL, INPUT);

    // 1 датчик на 1 выходе - через плату HW-080 ... 410 показания
    // неподключенные 1023- проблемы с землей 2 датчик на 4 выходе - v 1.2 3
    // датчик на 7 выходе - TDR 4 датчик - нужен резистор !!!!!!!!!! туду

    // туду проверить без питания и без подключения к порту

    // пины прерывания int0 2 int1 3 int2 21 int3 20 int4 19 int5 18
    // все digital пины поддерживают прерывания через
    // https://github.com/NicoHood/PinChangeInterrupt помечать данные volatile,
    // если надо совмещать данные программы и прерывания безопасное чтение
    // многобайтовых переменных через отключение прерываний... noInterrupts();
    // ... interrupts();
    //
  }

  void loopSensors(AwLogging& logger, State& state) {
#ifdef DEBUG_LOG
    logger.writeln(F("Start loop sensors."));
#endif
    loopSoilMoistureSensors(state);
    sht31.read(false);
    state.temperature = sht31.getTemperature();
    state.humidity = sht31.getHumidity();

    int waterLevel = digitalRead(PIN_WATER_LEVEL);
    // state.hasWaterLevel = waterLevel == HIGH;
  }

  void tmpLoop(State& state) {
    loopSoilMoistureSensors(state);
    Serial.print(F("plants:"));
    for (int i = 0; i < PLANTS_AMOUNT; i++) {
      Plant p = state.plants[i];
      if (p.isOn != PLANT_IS_ON) {
        continue;
      }
      Serial.print(' ');
      Serial.print(i);
      Serial.print('=');
      Serial.print(p.originalValue);
    }
    Serial.println();
  }
};

/*
1023 - не подключен либо воздух
950-1013 - сухо
150-270 - в воде, начинается с 100 и "разгоняется", минуты 3 на устаканиться
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

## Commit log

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2025-09-08 [NEW] победил часы реального времени и подключение экрана
    в боях с параллельной работой экрана и логирования
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2025-09-16 [NEW] добавил скетчи для esp8266 и интеграцией с yandex iot
    - победил SD карту не на SPI (чтобы экра не мешал)
    - нашел гугловскую стилистику форматирования кода
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2025-09-26 [REF] финализировал пины часов, экрана, SD карты и управление клапанами через сдвиговые регистры
2025-09-29 [NEW] победил чтение кнопки принудительного пролива и включения растения
    + заготовка логики
    + заготовка настроек приложения из локальной сети
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2025-10-02 [REF] сбор данных, какая-то визуализация на экране, подготовка клапан+двигатель
    подготовка к работе в режиме "вкл на 17сек для 20мл раз в день"
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2025-11-13 [NEW] коммуникация длинными строками с подтверждением, время с esp в ардуино, флаг включенной помпы
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2025-11-20 [SHIT] исправление косяков мержинга
    [AwLogging.h, State.h, sketch_auto_watering.ino]
2025-11-20 [NEW] налажена работа с датчиком расхода воды + реализована функция полива одного растения
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2026-02-11 [BUG] утранение багов нового боевого запуска
    [AwLogging.h, EspMain.cpp, Pomp.h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]
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2026-03-05 [REF] переделал сбор данных на графики с фильтрацией значений "через медиану"
    не работает, поэтому добавил отладочной информации
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2026-04-09 [BUG] fix graph crash: division by zero + out-of-bounds in PointsHoler
    - Graph::plot: stepY=max(1,...) чтобы не делить на 0 при одной точке
    - PointsHoler: индекс graphId*PLANTS_AMOUNT исправлен на graphId*MEDIAN_NUM_POINTS
    - PointsHoler: исправлен внешний цикл пузырьковой сортировки (i от 0, не от start)
    - Добавлены тесты на десктопе через Docker (test/test_graph/, test/stubs/)
    [EspMain.cpp, State.h]
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2026-05-24 [NEW] контроль клапанов через датчик тока ACS712
    Реализованы два сценария использования:
    1. Ручная проверка всех активных клапанов (Telegram-команда
    ESP_COMMAND_CHECK_VALVES и кнопка check) — checkAllActiveValves
    отчитывается в Telegram по каждому клапану: "Valve check OK/FAIL:
    plant0 OK, plant1 FAIL, ...".
    2. Мониторинг во время полива — buildWaterReport включает
    "Amperage delta: 150mA (OK/DISCONNECTED)" в общую сводку
    waterPlant и ручного полива.
    Подробности эк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
    [Pomp.h, State.h, sketch_auto_watering.ino]
2026-05-24 [NEW] попап с результатом проверки клапанов на экранчике + sleepWithWdt
    Кнопка check теперь не только шлёт результат checkAllActiveValves в
    Telegram, но и показывает его на экранчике через drawScreenMessage с
    авто-возвратом к loopScreen через 5 секунд (тот же паттерн, что и в
    ручном поливе через тумблер).
    Заодно вынес delay+wdt_reset в утилиту sleepWithWdt: спит кусочками по
    1с с резетом между ними и в начале/конце. Применил в двух мест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
2026-05-24 [REF] уменьшил размер шрифта попапа на экранчике с 4 до 3
    Длинная строка результата checkAllActiveValves не помещалась на экран
    при textSize 4.
2026-05-25 [FIX] починил инициализацию SD: sd/softSpi теперь поля класса, sd.open вместо file.open
    [AwLogging.h]
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2026-07-20 [FIX] пачка 1 ревью: валидация команд, whitelist telegram, wdt, таймзона
    - валидация plantId (0..15) и cap 200ml на Mega: раньше /config plant99
    писал за пределы массива plants, /water plant99 давал UB в bitWrite
    - whitelist chat id в telegram + флаг отключения защиты
    - wdt_reset в readNextChunk: деградация UART-связи роняла Mega в ребут
    - timeOut() сравнивал state с COMMUNICATION_TIME_OUT(10) вместо
    STATE_TIMEOUT(5) - ветка восстановления была мертва
    - медиана PointsHoler брала элемент выше ме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
    [Communication.cpp, Communication.h, EspMain.cpp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]
2026-07-20 [REF] пачка 2 ревью: include guard'ы, DEBUG_LOG и SPI_DRIVER_SELECT в build_flags
    - include guard'ы во всех хедерах src/, inline на свободных функциях
    State.h и out-of-class методах AwClock (ODR-безопасность)
    - DEBUG_LOG переехал из Communication.h в build_flags обоих окружений
    - SPI_DRIVER_SELECT=2 задаётся build-флагом: ручная правка SdFatConfig.h
    в библиотеке больше не нужна (проверено сборкой с чистой SdFat,
    сток имеет дефолт 0), шаг убран из readme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
2026-07-20 [REF] пачка 3 ревью: разбивка Pomp, общий парсер команд, const-ссылки, snprintf
    - Pomp разбит на модули: Valves (74HC595), FlowMeter (YF-S401),
    CurrentSensor (ACS712); Pomp остался оркестратором с прежним API
    - общий parsePlantAmountCommand для /water и /config (+ проверка
    суффикса ml), serialCommandWater/serialConfig слиты в serialPlantCommand
    - State/Plant/JsonDocument передаются по const-ссылке вместо копий
    - buildWaterReport и конфиг-лист собираются через snprintf_P в буфер
    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
2026-07-20 [REF] пачка 4 ревью: SD-лог, экран без мигания, EEPROM-страховка, графики
    - LOG.txt держится открытым, flush раз в 5с: open/close на каждую строку
    изнашивал FAT карты и тормозил loop
    - двойной analogRead после переключения мультиплексера датчиков влажности
    (первый замер тащил заряд соседнего канала)
    - экран без мигания: fillScreen только при смене фона/после попапа,
    строки добиваются пробелами, строка датчиков ра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
2026-07-20 [NEW] пачка 5 ревью: native-тесты парсера команд + актуализация теста медианы
    - парсер telegram-команд вынесен в src/CommandParser.h (inline, чистая
    логика) и покрыт 11 тестами (test/test_command_parser)
    - тест медианы PointsHoler обновлён под фикс индекса (400, не 500)
    - стаб Arduino.h расширен: startsWith/endsWith/indexOf/substring/
    charAt/toInt/isDigit
    - в platformio.ini задокументирован запуск тестов через ssh deb
    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
2026-07-20 [FIX] по ревью Kimi: обход валидации через переполнение, SD-восстановление, нулевой стейт регистров
    - закрыт обход валидации 16-битным усечением: /water plant65536 давал
    id=0, 65640ml пролезал под cap. Три слоя: cap 6 цифр в парсере,
    checkPlantCommandBounds на ESP (внятное сообщение), long вместо int
    в isValidPlantCommand на Mega
    - AwLogging: при ошибке записи хэндл закрывается и переоткрывается —
    вернулось самовосстановление после пе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
    [AwLogging.h, EspMain.cpp, Valves.h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]
2026-07-20 [DOC] архитектура MQTT-переезда: ADR-0001, глоссарий, план, конфиги скиллов
    Решения грилинг-сессии: ESP headless, один локальный Mosquitto (Dealgate
    напрямую отменён), aw-server (Python) на серваке — бот + мост логов в Loki.
    План 2026-07-04 помечен superseded. Тикеты: #11 (спека) + #12–#18.
2026-07-20 [REF] #13: вырезаем мёртвое из ESP — Gyver, Telegram/TLS, Yandex IoT
    Готовим прошивку ESP к MQTT-слою (#16/#17): ESP становится headless-шлюзом
    (OTA + UART), веб-морда и внешние интеграции уходят на сервак (ADR-0001).
    - Удалены SettingsGyver + sets::Logger (веб-морда, PlotStack, кнопка Confirm,
    мёртвый updatedSettings), DEVFULL и ветка #else.
    - Удалены UniversalTelegramBot и весь TLS (WiFiClientSecure, BearSSL):
    telegramBot, whitelist чатов, logTelegram, loopTelegram,
    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
2026-07-20 [NEW] aw-server: ядро-роутер + мост логов aw/log/# → Loki
    Первая роль сервиса (issue #14): чистый Router (aw_server/core.py) превращает
    входящее MQTT-сообщение в список эффектов LokiPush — без транспортных зависимостей,
    тестируется pytest без живого брокера/HTTP (12 тестов, tests/). Адаптеры —
    mqtt_bridge.py (paho-mqtt, авто-reconnect с backoff, подписка aw/log/#) и loki.py
    (HTTP-пуш в push API, ошибки логируются с полным stacktrace и не роняют сервис).
    Битый/неполный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
2026-07-20 [NEW] MQTT-слой ESP: лог-поток в aw/log/esp с RAM-кольцом, LWT aw/online (issue #16)
    ESP подключается к брокеру (PubSubClient, учётка esp, неблокирующий
    реконнект по таймеру 5с). LWT aw/online (retained, "0"), после коннекта
    явно публикуется "1" retained. Логгер (EspLogger) собирает строки
    Print-интерфейса построчно и публикует JSON {ts,lvl,msg} в aw/log/esp:
    при живом соединении — сразу, при обрыве — в новый header-only модуль
    LogRing (RAM-кольцо ~3КБ, без Arduino-зависим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
    [EspMain.cpp]
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2026-07-20 [NEW] MQTT-контур ESP: Команды из aw/cmd, retained Стейт, События в aw/event (issue #17)
    Завершающий тикет прошивки: ESP подписан на aw/cmd (QoS1) и валидирует
    Команды (esp_water/esp_plant_conf/esp_daily/esp_check_valves/esp_graphs)
    перед форвардом в UART; невалидные (границы id/объёма, битый JSON,
    неизвестная команда) отбиваются Событием-отказом в aw/event + логом.
    esp_graphs рендерит ASCII через существующие Graph/PointsHoler/lastPlotPoints
    и отвечает по одному aw/event на ра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
    [EspMain.cpp]
2026-07-20 [FIX] по внутреннему ревью: FIFO досылки, свежесть retained-стейта, честный ACK
    Прошивка: flushPending через peek/dropFront (сбой publish не ломает порядок),
    маркер потерь сбрасывается после подтверждения, буфер досылки 640Б (влезает
    kMaxLineLen после JSON-экранирования), таймаут TCP-connect 2с (молчащий брокер
    не держит loop по 5с), arduino_tg без message оставляет след в логах,
    strcmp вместо String, комментарии по глоссарию (aw-server, не «бот»).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
    [EspMain.cpp]
2026-07-20 [FIX] по ревью GLM: офлайн-ESP в ACK, whitelist fail-fast, retained-возраст, диагностика Loki
    - ACK команды предупреждает, когда aw/online=0 (clean-session+QoS0: брокер
    выбрасывает команду для офлайн-ESP — подтверждение было ложным);
    - пустой после парсинга whitelist роняет старт (бот-зомби, игнорирующий всё);
    - retained-redelivery того же aw/state при кратком реконнекте paho не затирает
    известный возраст стейта (None — только для отличающегос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
2026-09-17 [NEW] корпус: параметрический скрипт генерации и модели под печать
    generate_case.py строит корпус (aw_case_body.stl, aw_case_lid.stl) и
    чертёж aw_case_drawing.png. Лежало вне гита с июля.
    [aw_case_body.stl, aw_case_lid.stl]
2026-09-17 [DOC] фотографии собранной установки
    Снимки железа as-is: платы, клапанное хозяйство, разводка. Пригодятся к
    доработкам следующего корпуса (issue #21).
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2026-09-21 [FIX] свой коэффициент расхода на каждую помпу
    Замеры показали, что помпы льют по-разному: 2.1 мл/с у первой против
    3.2 мл/с у второй (прежние общие 7.7 мл/с не соответствовали ни одной).
    Вместо одной константы теперь две и метод pumpFlowMlPerSec(pumpIdx),
    который выбирает нужную по позиционному номеру помпы.
    Из-за этого в waterPlant выбор помпы переехал выше расчёта числа
    итераций: на пробе резерва полив и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
    [Pomp.h]
2026-09-23 [FIX] связь Mega↔ESP: сообщение не теряется при сбое, отчёты дневного полива уходят по ходу
    Дневной полив 23.09 потерял в Telegram отчёты по растениям 0, 1, 3 и 5,
    хотя полито было всё. Разбор по логам ESP в Loki:
    - runDailyCommand держал loop() почти две минуты, отчёты копились в
    очереди и ушли пачкой в конце; на пачке связь сорвалась (обрезанные и
    склеенные сообщения, две минуты перекидывания «hellow world»);
    - при та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
    [Communication.cpp, sketch_auto_watering.ino]
2026-09-25 [FIX] память Mega: слоты очереди связи освобождают буфер, ESP не шлёт логи в UART
    Свободная RAM Mega падала ступеньками с ~4.9КБ до ~200 байт, и при
    нехватке памяти в ESP уходили пустые сообщения — так 25.09 пропал отчёт
    дневного полива по растению 0. Причина: слот очереди «очищался» через
    = F(""), а AVR-шный String::reserve(0) оставляет выделенный буфер, так что
    каждый из 10 слотов навсегда держал память под самое дл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
    [Communication.cpp, EspMain.cpp, sketch_auto_watering.ino]
